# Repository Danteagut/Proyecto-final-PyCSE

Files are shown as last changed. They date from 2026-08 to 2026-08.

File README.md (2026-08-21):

Motor Dron — Control de Altura por Realimentación Negativa

Trabajo práctico de posgrado en Sistemas Embebidos. Control de altura en lazo cerrado de un "drone conceptual" (motor DC + hélice sobre un banco de pruebas), implementado sobre un STM32F446RE (Nucleo-F446RE), con telemetría y consigna remota por Bluetooth Low Energy y un dashboard en Node-RED.

Qué hace

Un sensor ultrasónico HC-SR04 mide la altura real del conjunto. Un controlador PID corre en el STM32 a 10 Hz, compara esa altura contra un setpoint (objetivo) recibido de forma remota, y ajusta el empuje del motor (PWM sobre un puente H L298N) para sostenerlo en esa altura. El setpoint se manda con un simple comando de texto (HEIGHT:<cm>) desde un celular por BLE o desde la PC por el propio cable USB del ST-Link, y la telemetría se puede visualizar en tiempo real en un dashboard de Node-RED.

 objetivo (cm) ──►(+)──► error ──► PID ──► saturación ──► motor (PWM) ──► planta (altura real)
                   ▲                                                            │
                   └──────────────────── retroalimentación negativa (HC-SR04) ─────┘

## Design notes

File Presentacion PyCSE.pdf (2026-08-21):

# Control de altura por realimentación negativa

# Motor Dron TP — Sistemas Embebidos de Posgrado

### Desarrollo de drone para control de cultivos y desmalezado

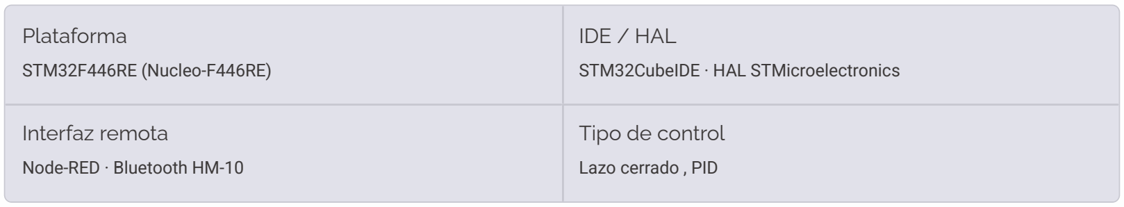
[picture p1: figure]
Plataforma; STM32F446RE (Nucleo-F446RE); IDE / HAL; STM32CubeIDE · HAL STMicroelectronics; Interfaz remota; Node-RED · Bluetooth HM-10; Tipo de control; Lazo cerrado , PID

# Punto de partida: El proyecto original

El firmware inicial consistía en un único main.c que combinaba dos perifericos independientes, sin ningún lazo de control entre ellos.

# Experimento 1 — Control de velocidad motor DC

### - ADC1 en PA4 (canal 4) con filtro de promedio móvil de 16

### muestras - PWM de 1 kHz generado por TIM2_CH1 / PA5 → driver L298N (ENA)

### - Sentido fijo adelante: IN1/IN2 en PB5/PB10

### - Velocidad controlada directamente por el potenciómetro analógico

# Experimento 2 — Medición de distancia HC-SR04

### - TIM1 en modo Input Capture: TRIG en PA9, ECHO en

### PA8/TIM1_CH1 - Cálculo de ancho de pulso → distancia en cm - Reporte por USART2 a 115200 baud al ST-Link (terminal serie)

### - Frecuencia de muestreo: ~1 Hz

Punto crítico: Motor y sensor NO estaban conectados entre sí. La distancia se medía pero no influía en la velocidad. No existía lazo de control, Bluetooth ni Node-RED.

# Objetivo del rediseño

Transformar el banco de pruebas en un verdadero sistema de control automático en lazo cerrado, eliminando la entrada manual del potenciómetro y habilitando operación remota.

### 1 Retroalimentacion real

La distancia medida por el HC-SR04 se convierte en la
variable de retroalimentación que ajusta automáticamente velocidad y sentido del motor en cada ciclo de control.

### 2 Setpoint remoto

La altura objetivo (setpoint en cm) es configurable de forma remota por Bluetooth desde un dashboard Node-RED, sin recompilar ni reconectar el hardware.

### 3 Telemetría continua

El sistema emite telemetría a 2 Hz (altura, setpoint, velocidad aplicada) hacia Node-RED para visualización en tiempo real y análisis de respuesta al escalón.

### Diagrama de bloques — Lazo de realimentación negativa

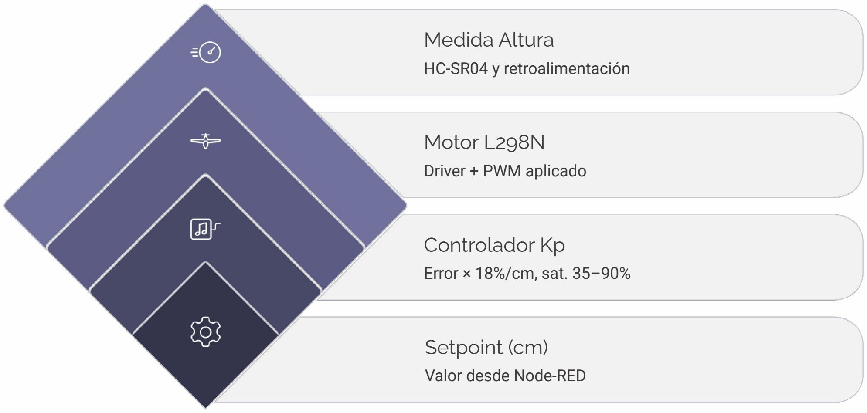
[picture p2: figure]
Medida Altura; HC-SR04 y retroalimentación; Motor L298N; Driver + PWM aplicado; Controlador Kp; Error × 18%/cm, sat. 35–90%; Setpoint (cm); Valor desde Node-RED

El error se calcula como e = setpoint − altura_actual. Una zona muerta de ±0.5 cm evita chattering por ruido de medición. El lazo opera a 10 Hz; la telemetría se emite a 2 Hz de forma desacoplada.

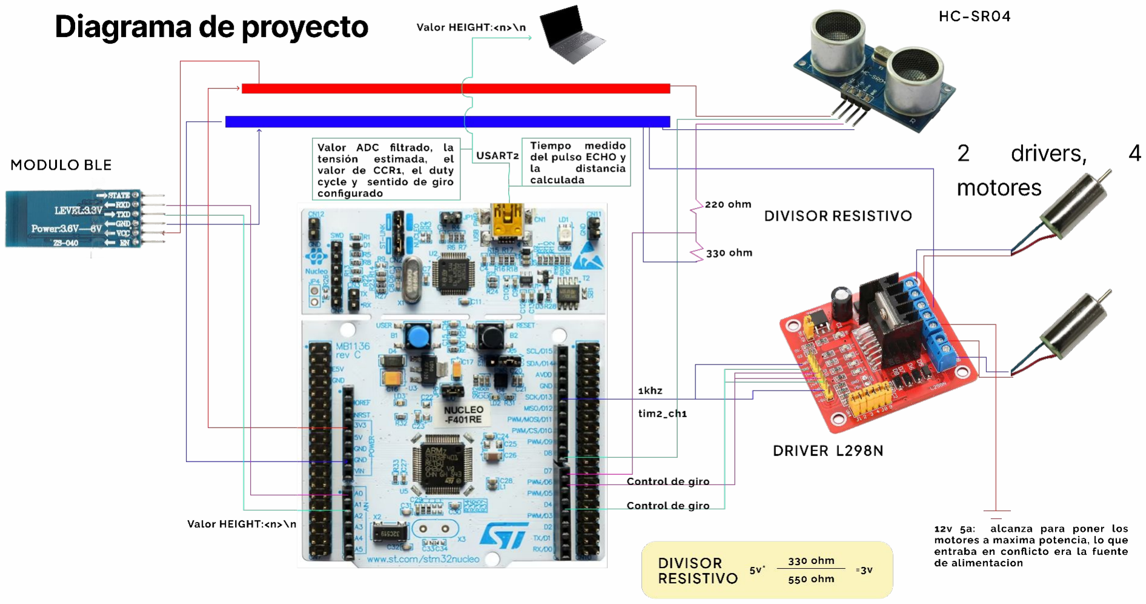
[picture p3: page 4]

# Arquitectura de software: La modularidad

La reorganización completa en módulos independientes (carpetas Src/ e Inc/) es la decisión arquitectónica central del rediseño. Cada módulo tiene responsabilidad única, es testeable de forma aislada y reemplazable sin afectar al resto.

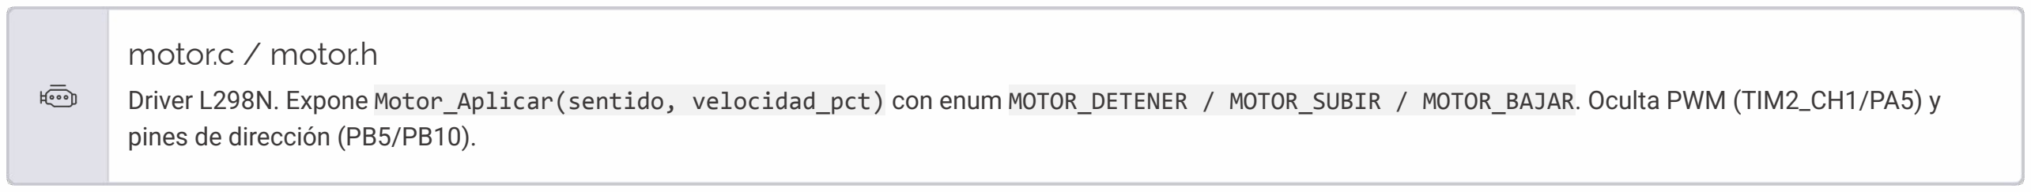
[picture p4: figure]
motor.c / motor.h; pines de dirección (PB5/PB10).

Driver L298N. Expone Motor_Aplicar(sentido, velocidad_pct) con enum MOTOR_DETENER / MOTOR_SUBIR / MOTOR_BAJAR. Oculta PWM (TIM2_CH1/PA5) y

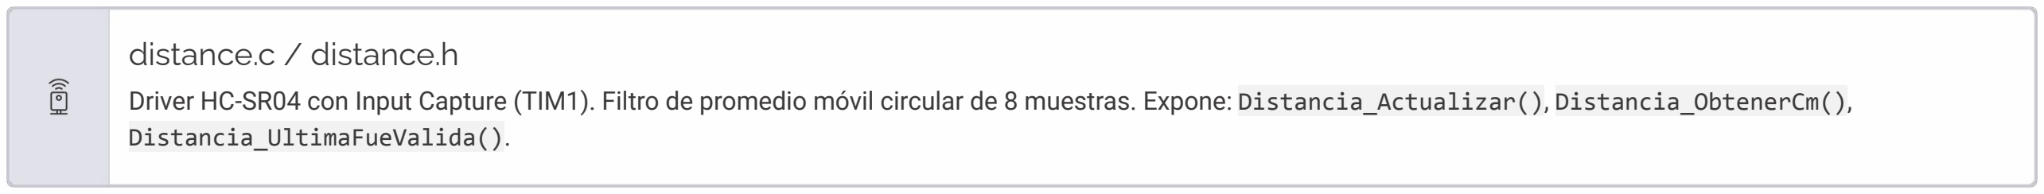
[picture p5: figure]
distance.c / distance.h; Distancia_UltimaFueValida().

Driver HC-SR04 con Input Capture (TIM1). Filtro de promedio móvil circular de 8 muestras. Expone: Distancia_Actualizar(), Distancia_ObtenerCm(),

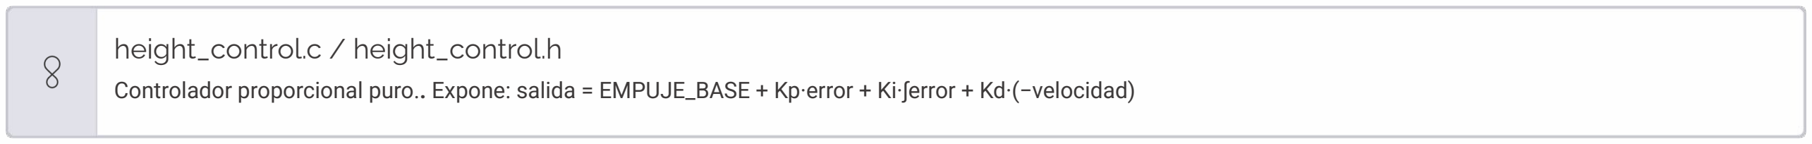
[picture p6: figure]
height_control.c / height_control.h

Controlador proporcional puro.. Expone: salida = EMPUJE_BASE + Kp·error + Ki·∫error + Kd·(−velocidad)

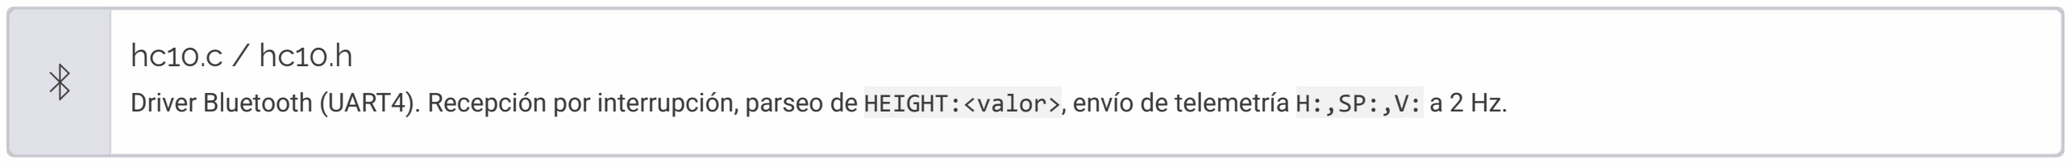
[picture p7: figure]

Driver Bluetooth (UART4). Recepción por interrupción, parseo de HEIGHT:<valor>, envío de telemetría H:,SP:,V: a 2 Hz.

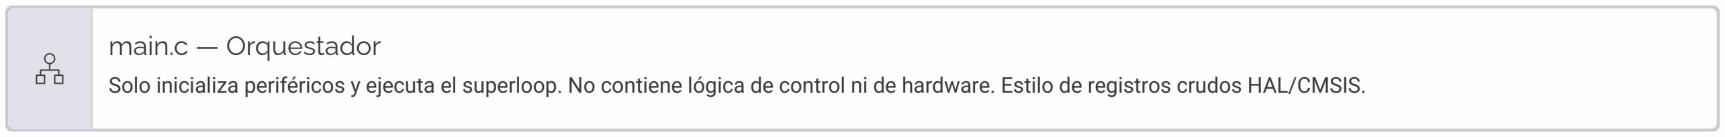
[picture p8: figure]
main.c — Orquestador

Solo inicializa periféricos y ejecuta el superloop. No contiene lógica de control ni de hardware. Estilo de registros crudos HAL/CMSIS.

# Tabla de conexionado físico (pines)

Asignación completa de pines del Nucleo-F446RE para el sistema integrado. GND común obligatorio entre fuente de motor y STM32 (falla real detectada y corregida en puesta en marcha).

Función | Pin Nucleo | Periférico / Notas | Subsistema
ENA (PWM) | PA5 | TIM2_CH1, 1 kHz, duty cycle 35–90% | Motor L298N
IN1 (dirección) | PB5 | GPIO salida digital | Motor L298N
IN2 (dirección) | PB10 | GPIO salida digital | Motor L298N
TRIG | PA9 | GPIO salida, pulso 10 µs | HC-SR04
ECHO | PA8 | TIM1_CH1, Input Capture | HC-SR04
TX módulo BT | PA1 | UART4_RX, 9600 baud | Bluetooth Hm-10 (bt05)
RX módulo BT | PA0 | UART4_TX, 9600 baud | Bluetooth Hm-10 (bt05)
TX debug | PA2 | USART2, 115200 baud (ST-Link) | Debug
RX debug | PA3 | USART2, 115200 baud (ST-Link) | Debug

USART2 y UART4 son periféricos separados deliberadamente para evitar contención entre tráfico de debug (115200 baud) y tráfico Bluetooth (9600 baud). Nunca comparten bus.

# Sistema de control: Lazo de realimentación negativa

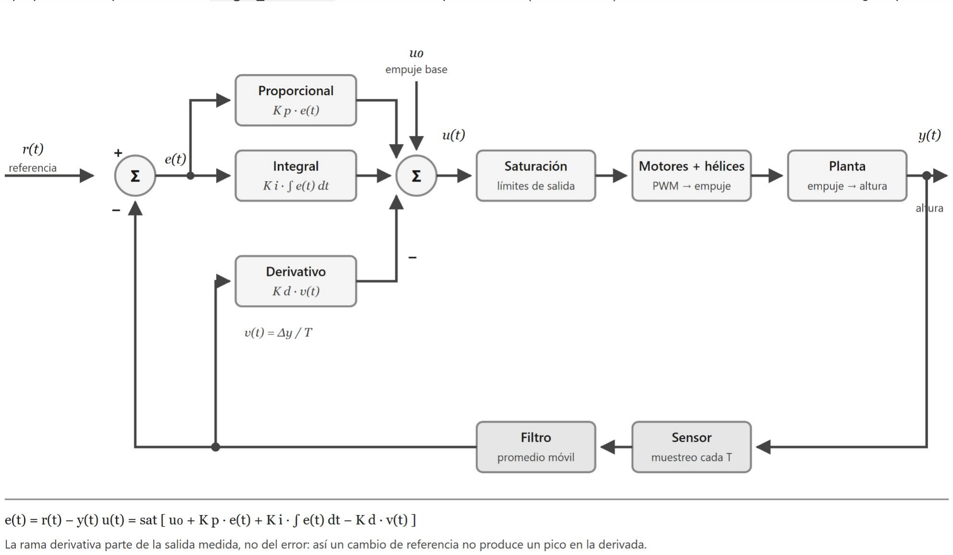
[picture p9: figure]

Ley de control proporcional implementada en height_control.c. El controlador opera a 10 Hz (cada 100 ms), frecuencia aumentada desde 1 Hz original para reducir overshoot.

# Sistema de control: Lazo de realimentación negativa

Ley de control proporcional implementada en height_control.c. El controlador opera a 10 Hz (cada 100 ms), frecuencia aumentada desde 1 Hz original para reducir overshoot.

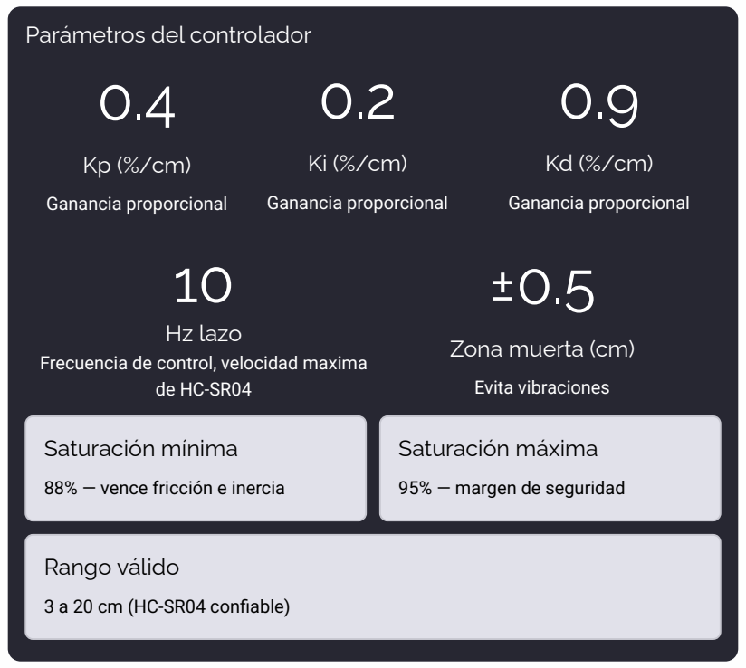
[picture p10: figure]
Parámetros del controlador 0.4; Ganancia proporcional; Zona muerta (cm); Evita vibraciones; Hz lazo; Frecuencia de control, velocidad maxima de HC-SR04; Saturación mínima; 88% — vence fricción e inercia; Saturación máxima; 95% — margen de seguridad; Rango válido; 3 a 20 cm (HC-SR04 confiable)

# Comunicación Bluetooth: Protocolo y hardware

Enlace Bluetooth completo agregado al sistema. Implementado sobre UART4 (PA0/PA1) a 9600 baud. El hardware real identificado es un HM-10 (breakout ZS-040, Bluetooth clásico/SPP).

## Protocolo de entrada — Comando remoto desde Node-RED

HEIGHT:<valor_cm>\n

Ejemplo: HEIGHT:15\n fija el setpoint a 15 cm. El módulo hc10.c recibe por interrupción y parsea el token HEIGHT: antes de llamar a ControlAltura_FijarObjetivoCm().

## Protocolo de salida — Telemetría a 2 Hz

H:<altura>,SP:<setpoint>,V:<velocidad_pct>\n

## Puesta en marcha del módulo HM-10

## Identificación del hardware

El módulo real es HM-10 (BT05). Diferencia crítica: utiliza la estructura de un modulo hc05 entonces la computadora no lo reconoce como ble y no puedo enviar comandos

## Firmware puente standalone

Herramienta de soporte: firmware que usa el ST-Link como adaptador USB-TTL para enviar comandos AT al HM-10

USART2 emite simultáneamente mensajes legibles por humanos a 115200 baud para depuración en terminal serie, en paralelo al tráfico Bluetooth.

# Dashboard en Node-RED: Interfaz de usuario remota

Flujo control-altura-dashboard.json — HMI/SCADA, permite ensayos sin recompilar y separa la visualización de la lógica de control embebida.

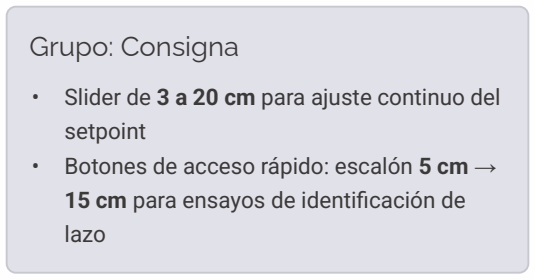
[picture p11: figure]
Grupo: Consigna; setpoint; 15 cm para ensayos de identificación de; lazo

- Slider de 3 a 20 cm para ajuste continuo del
- Botones de acceso rápido: escalón 5 cm →

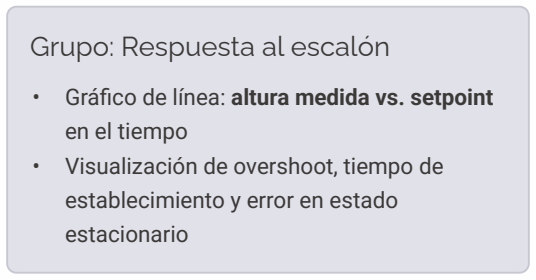
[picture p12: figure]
Grupo: Respuesta al escalón; en el tiempo; • Visualización de overshoot, tiempo de; establecimiento y error en estado; estacionario

- Gráfico de línea: altura medida vs. setpoint

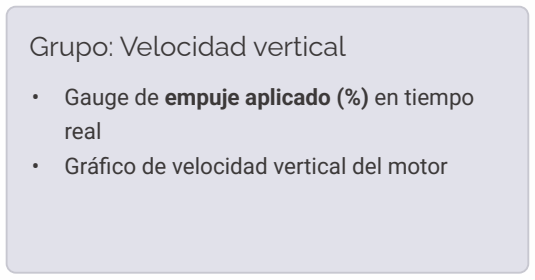
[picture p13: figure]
Grupo: Velocidad vertical; real

- Gauge de empuje aplicado (%) en tiempo
- Gráfico de velocidad vertical del motor

## Nodo function — "Formatear HEIGHT"

## Nodo function — "Parsear telemetría"

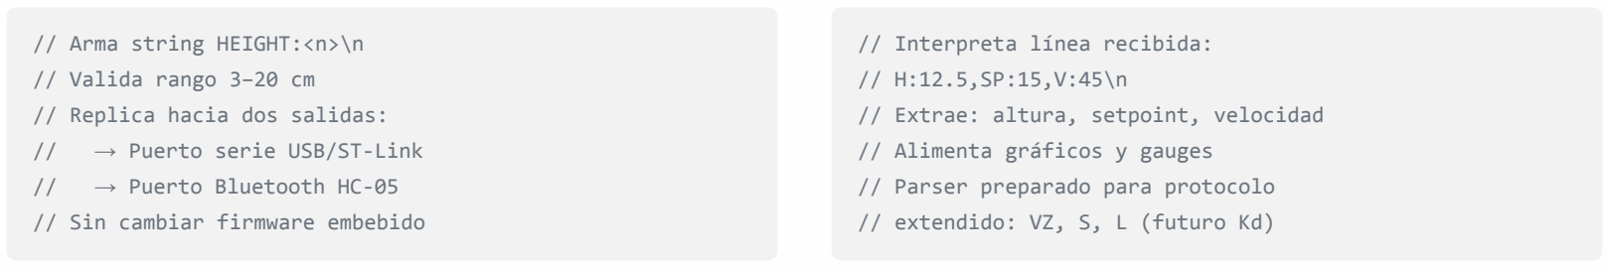
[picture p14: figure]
// Arma string HEIGHT:<n>\n; // Valida rango 3–20 cm; // Replica hacia dos salidas:; → Puerto serie USB/ST-Link; → Puerto Bluetooth HC-05; // Sin cambiar firmware embebido; // Interpreta línea recibida:; // Extrae: altura, setpoint, velocidad; // Alimenta gráficos y gauges; // Parser preparado para protocolo; // extendido: VZ, S, L (futuro Kd)

# Valor K : Valores 01

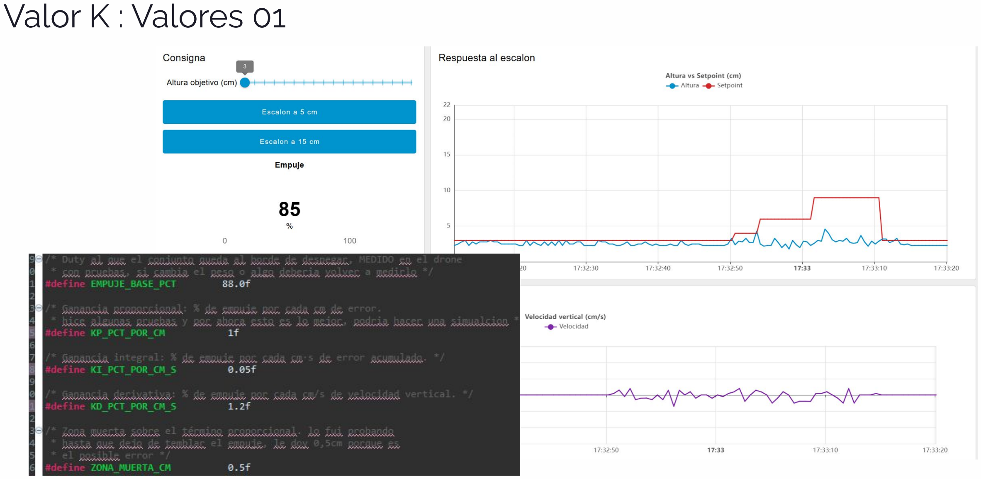
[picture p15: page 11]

# Valor K : Valores 02

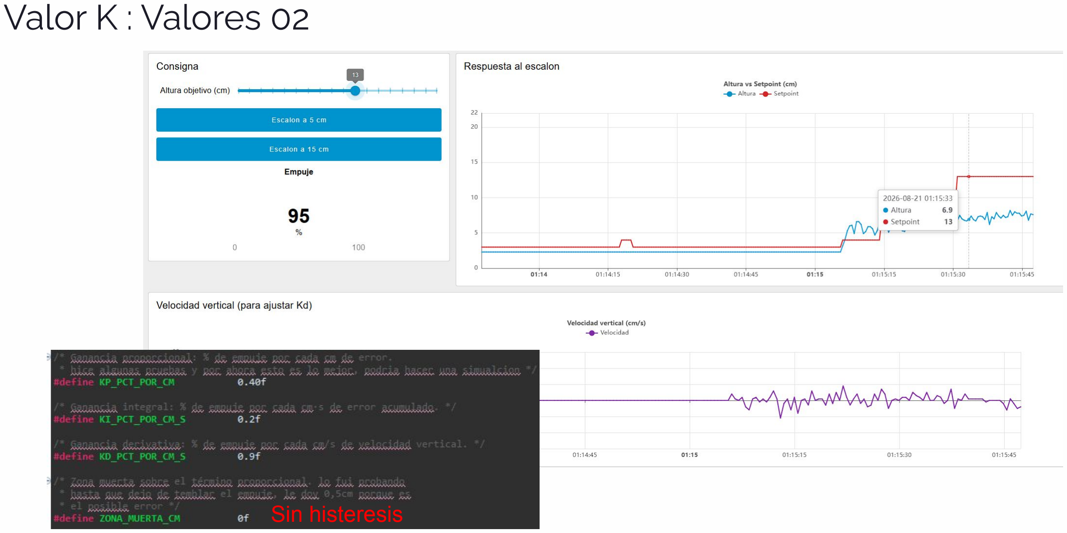
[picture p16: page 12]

## Sin histeresis

# Valor K : Valores 03

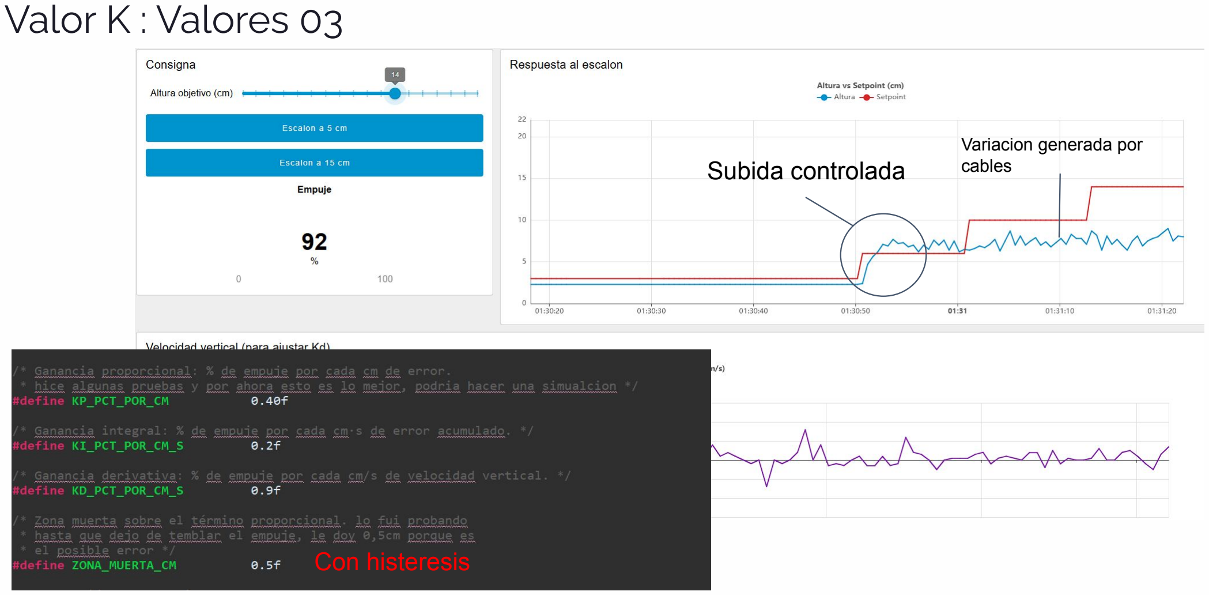
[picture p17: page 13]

## Subida controlada

### Variacion generada por cables

## Con histeresis

# Tabla comparativa: Proyecto original vs. Rediseñado

El salto cualitativo entre ambas versiones abarca organización del código, arquitectura de control, comunicaciones e interfaz de usuario. La tabla resume las siete dimensiones de comparación.

Aspecto | Proyecto original | Proyecto rediseñado
Organización del código | Único main.c monolítico, sin separación de responsabilidades | Módulos separados: motor.c, distance.c, height_control.c, hc10.c, main.c orquestador
Entrada del sistema | Potenciómetro analógico (ADC manual, PA4) | Setpoint remoto por Bluetooth o directo desde dashboard Node-RED (HEIGHT:<n>\n)
Relación motor–sensor | Independientes, sin lazo. Distancia medida pero ignorada por el motor | Lazo cerrado de realimentación negativa con control proporcional (Kp = 18 %/cm)
Frecuencia de actualización | Sensor a ~1 Hz, sin control automático | Control a 10 Hz, telemetría a 2 Hz, desacoplados
Comunicación | Solo USART2 a 115200 baud (debug local, terminal serie) | USART2 (debug) + UART4/HC-05 Bluetooth (comando y telemetría remota, 9600 baud)
Interfaz de usuario | Ninguna (terminal serie cruda, lectura manual) | Dashboard Node-RED: slider, botones de escalón, gráficos de respuesta, gauge de empuje
Alcance de motores | 1 motor / 1 canal L298N en firmware único | 1 motor en firmware principal + variante experimental de 4 motores (variante_4_motores) aislada del código de producción

lazo cerrado proporcional con zona muerta y

De terminal serie local a protocolo Bluetooth protocolo extendido VZ/S/L, variante de 4

# Puntos de mejora

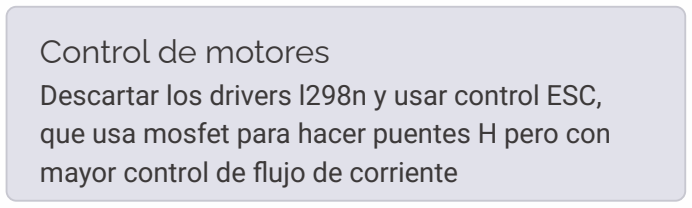
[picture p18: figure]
Control de motores; mayor control de flujo de corriente

Descartar los drivers l298n y usar control ESC,

## que usa mosfet para hacer puentes H pero con

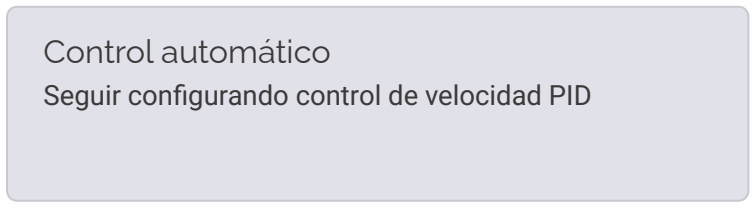
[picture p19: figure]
Control automático

## Seguir configurando control de velocidad PID

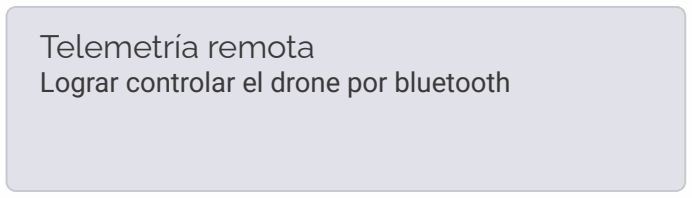
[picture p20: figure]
Telemetría remota; Lograr controlar el drone por bluetooth
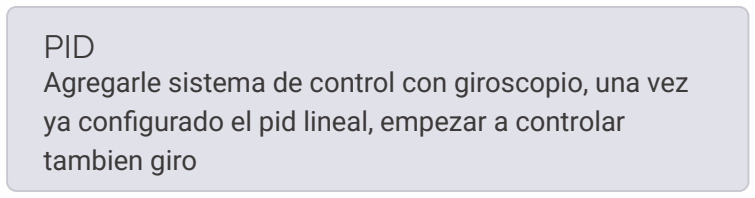
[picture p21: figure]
PID; tambien giro

## Agregarle sistema de control con giroscopio, una vez ya configurado el pid lineal, empezar a controlar

# Muchas gracias

# Dante Gutierrez LSE / PyCSE 21/08/2026

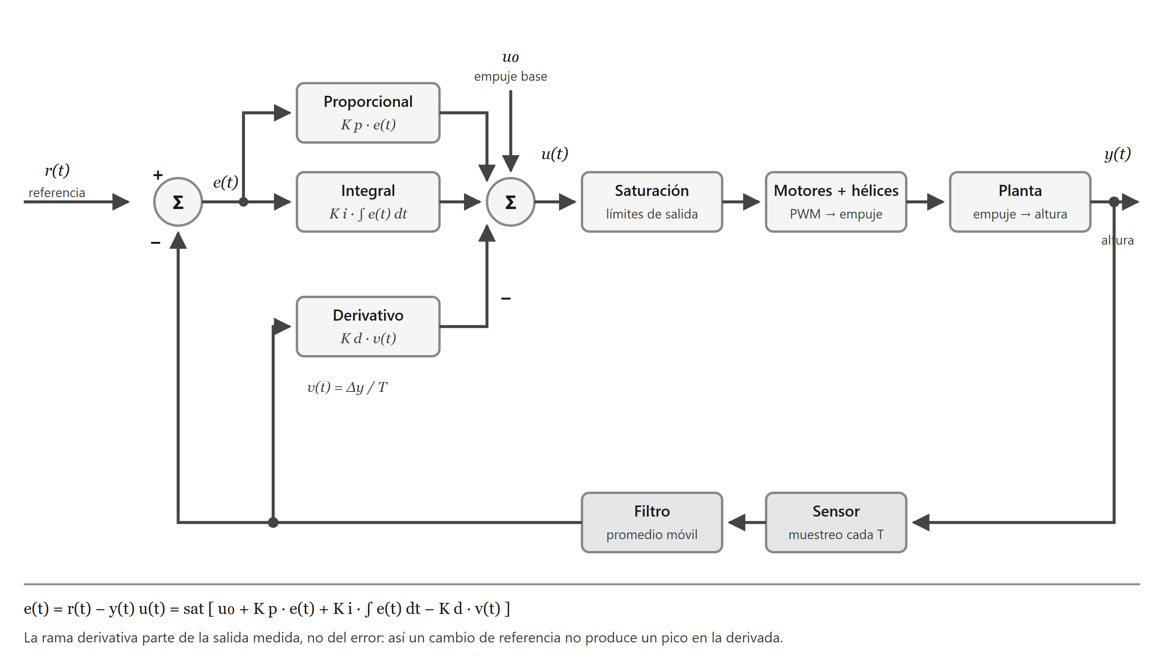
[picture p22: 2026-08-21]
Documentacion/diagrama-control-pid.png

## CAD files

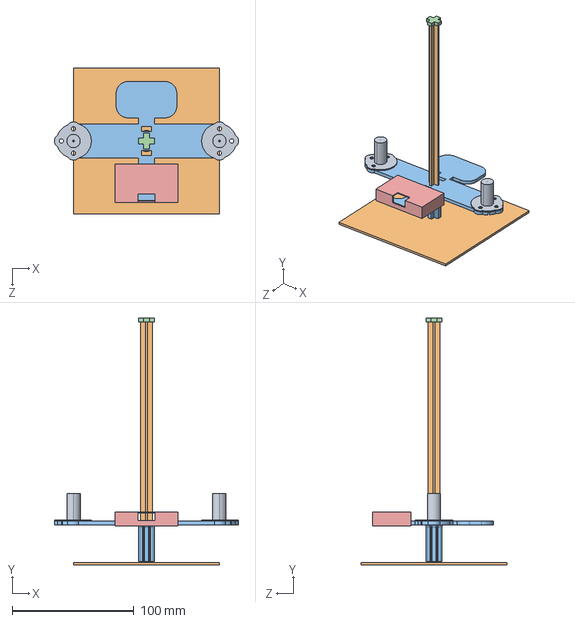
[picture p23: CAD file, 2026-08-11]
Introduccion a sistemas embebidos/Modelado de drone.STEP
151.5 x 203.2 x 120.0 mm

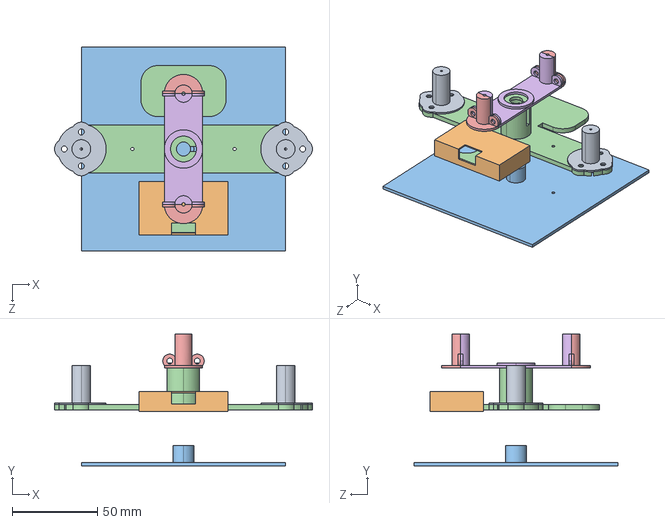
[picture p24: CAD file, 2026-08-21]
Modelado de drone.STEP
151.5 x 77.5 x 120.0 mm

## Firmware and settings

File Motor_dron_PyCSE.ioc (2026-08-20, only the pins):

Mcu.UserName=STM32F446RETx
PA0-WKUP.Signal=UART4_TX
PA1.Signal=UART4_RX
PA13.GPIO_Label=TMS
PA13.Signal=SYS_JTMS-SWDIO
PA14.GPIO_Label=TCK
PA14.Signal=SYS_JTCK-SWCLK
PA2.GPIO_Label=USART_TX
PA2.Signal=USART2_TX
PA3.GPIO_Label=USART_RX
PA3.Signal=USART2_RX
PA5.Signal=S_TIM2_CH1
PA8.Signal=S_TIM1_CH1
PA9.GPIO_Label=HCSR04_TRIG
PA9.Signal=GPIO_Output
PB10.GPIO_Label=L298N_IN2
PB10.Signal=GPIO_Output
PB3.GPIO_Label=SWO
PB3.Signal=SYS_JTDO-SWO
PB5.GPIO_Label=L298N_IN1
PB5.Signal=GPIO_Output
PC13.GPIO_Label=B1 [Blue PushButton]
PC13.Signal=GPXTI13
PC14-OSC32_IN.Signal=RCC_OSC32_IN
PC15-OSC32_OUT.Signal=RCC_OSC32_OUT
PH0-OSC_IN.Signal=RCC_OSC_IN
PH1-OSC_OUT.Signal=RCC_OSC_OUT

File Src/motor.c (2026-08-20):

#include "motor.h"
#include "main.h"

/* Driver L298N + PWM (TIM2_CH1/PA5) existente, modularizado.
 * La velocidad la determina el lazo proporcional de height_control,
 * no Node-RED ni el potenciómetro. */
#define PWM_PERIODO_CUENTAS               1000UL   /* ARR + 1 */

#define L298N_PIN_IN1                     5U       /* PB5  - D4 */
#define L298N_PIN_IN2                     10U      /* PB10 - D6 */

/* FORWARD (IN1=1,IN2=0) hace que la altura
 * medida por el sensor AUMENTE => FORWARD = MOTOR_SUBIR. */

/* Configura TIM2_CH1 sobre PA5 como salida PWM de 1 kHz (señal ENA del L298N). */
static void Configurar_PWM_TIM2_PA5(void)
{
    RCC->AHB1ENR |= RCC_AHB1ENR_GPIOAEN;
    (void)RCC->AHB1ENR;

    GPIOA->MODER &= ~(3UL << (5U * 2U));
    GPIOA->MODER |=  (2UL << (5U * 2U));
    GPIOA->OTYPER &= ~(1UL << 5U);
    GPIOA->OSPEEDR &= ~(3UL << (5U * 2U));
    GPIOA->OSPEEDR |=  (2UL << (5U * 2U));
    GPIOA->PUPDR &= ~(3UL << (5U * 2U));

    GPIOA->AFR[0] &= ~(0xFUL << (5U * 4U));
    GPIOA->AFR[0] |=  (1UL   << (5U * 4U));

    RCC->APB1ENR |= RCC_APB1ENR_TIM2EN;
    (void)RCC->APB1ENR;

    TIM2->CR1 &= ~TIM_CR1_CEN;

    TIM2->PSC = 83U;
    TIM2->ARR = 999U;
    TIM2->CNT = 0U;
    TIM2->CCR1 = 0U;

    TIM2->CCMR1 &= ~TIM_CCMR1_CC1S;
    TIM2->CCMR1 &= ~TIM_CCMR1_OC1M;
    TIM2->CCMR1 |=  (6UL << 4U);
    TIM2->CCMR1 |= TIM_CCMR1_OC1PE;

    TIM2->CCER &= ~TIM_CCER_CC1P;
    TIM2->CCER |=  TIM_CCER_CC1E;

    TIM2->CR1 |= TIM_CR1_ARPE;
    TIM2->CR1 &= ~TIM_CR1_CMS;
    TIM2->CR1 &= ~TIM_CR1_DIR;

    TIM2->EGR |= TIM_EGR_UG;
    TIM2->CR1 |= TIM_CR1_CEN;
}

/* Traduce un porcentaje de velocidad (0-100) al registro de comparación
 * del PWM, que es lo que define el duty cycle sobre el pin ENA. */
static void Motor_FijarVelocidadPorcentaje(uint32_t porcentaje)
{
    if (porcentaje > 100UL)
    {
        porcentaje = 100UL;
    }

    TIM2->CCR1 = (porcentaje * PWM_PERIODO_CUENTAS) / 100UL;
}

/* Configura PB5/PB10 como salidas digitales para IN1/IN2 del L298N. */
static void Configurar_PinesDireccion_L298N(void)
{
    RCC->AHB1ENR |= RCC_AHB1ENR_GPIOBEN;
    (void)RCC->AHB1ENR;

    GPIOB->MODER &= ~((3UL << (L298N_PIN_IN1 * 2U)) | (3UL << (L298N_PIN_IN2 * 2U)));
    GPIOB->MODER |=  ((1UL << (L298N_PIN_IN1 * 2U)) | (1UL << (L298N_PIN_IN2 * 2U)));
    GPIOB->OTYPER &= ~((1UL << L298N_PIN_IN1) | (1UL << L298N_PIN_IN2));
    GPIOB->OSPEEDR &= ~((3UL << (L298N_PIN_IN1 * 2U)) | (3UL << (L298N_PIN_IN2 * 2U)));
    GPIOB->PUPDR &= ~((3UL << (L298N_PIN_IN1 * 2U)) | (3UL << (L298N_PIN_IN2 * 2U)));
}

/* IN1=1, IN2=0: gira en el sentido que hace SUBIR la altura. */
static void Motor_GirarAdelante(void)
{
    GPIOB->BSRR = (1UL << L298N_PIN_IN2) | (1UL << (L298N_PIN_IN1 + 16U));
}

/* IN1=0, IN2=1: gira en el sentido que hace BAJAR la altura. */
static void Motor_GirarAtras(void)
{
    GPIOB->BSRR = (1UL << (L298N_PIN_IN2 + 16U)) | (1UL << L298N_PIN_IN1);
}

/* IN1=0, IN2=0: frena el motor (rueda libre / freno según el driver). */
static void Motor_Detener(void)
{
    GPIOB->BSRR = (1UL << (L298N_PIN_IN1 + 16U)) | (1UL << (L298N_PIN_IN2 + 16U));
}

/* Inicializa PWM y dirección, y deja el motor detenido con duty en cero. */
void Motor_Inicializar(void)
{
    Configurar_PWM_TIM2_PA5();
    Configurar_PinesDireccion_L298N();
    Motor_Detener();
    Motor_FijarVelocidadPorcentaje(0UL);
}

/* Aplica el resultado del lazo proporcional: primero el sentido en IN1/IN2
 * y después el duty del PWM sobre ENA. Al detener fuerza duty 0. */
void Motor_Aplicar(MotorComando_t sentido, uint8_t velocidad_pct)
{
    switch (sentido)
    {
        case MOTOR_SUBIR:
            Motor_GirarAdelante();
            Motor_FijarVelocidadPorcentaje((uint32_t)velocidad_pct);
            break;

        case MOTOR_BAJAR:
            Motor_GirarAtras();
            Motor_FijarVelocidadPorcentaje((uint32_t)velocidad_pct);
            break;

        case MOTOR_DETENER:
        default:
            Motor_Detener();
            Motor_FijarVelocidadPorcentaje(0UL);
            break;
    }
}

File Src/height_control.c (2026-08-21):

#include "height_control.h"
#include "motor.h"
#include <math.h>

/* ---------------------------------------------------------------------------
 * Lazo PID con base de empuje, para elevación por HÉLICES.
 *
 *   salida = EMPUJE_BASE + Kp·error + Ki·∫error + Kd·(−velocidad)
 *
 * Orden de importancia: primero D (estabilidad), después I (precisión).
 * Un P+I sin D sobre esta planta es inestable; el D tiene que estar puesto.
 *
 *  * ------------------------------------------------------------------------- */

/* El HC-SR04 no mide de forma confiable por debajo de ~2 cm. */
#define ALTURA_MIN_CM          3.0f
#define ALTURA_MAX_CM          20.0f

/* Duty al que el conjunto queda al borde de despegar, MEDIDO en el drone
 * con pruebas, si cambia el peso o algo deberia volver a medirlo */
#define EMPUJE_BASE_PCT        88.0f

/* Ganancia proporcional: % de empuje por cada cm de error.
 * hice algunas pruebas y por ahora esto es lo mejor, podria hacer una simualcion */
#define KP_PCT_POR_CM           0.40f

/* Ganancia integral: % de empuje por cada cm·s de error acumulado. */
#define KI_PCT_POR_CM_S         0.2f

/* Ganancia derivativa: % de empuje por cada cm/s de velocidad vertical. */
#define KD_PCT_POR_CM_S         0.9f

/* Zona muerta sobre el término proporcional. lo fui probando
 * hasta que dejo de temblar el empuje, le doy 0,5cm porque es
 * el posible error */
#define ZONA_MUERTA_CM          0.5f

/* Saturación de la salida, alrededor de la base.
 * El mínimo no es cero: conviene que las hélices sigan girando para no
 * pagar el tiempo de arranque cada vez que hay que descender. */
#define SALIDA_MIN_PCT         40.0f
#define SALIDA_MAX_PCT         95.0f

#define PERIODO_S              ((float)CONTROL_PERIODO_MS / 1000.0f)

static float   objetivo_cm         = ALTURA_MIN_CM;
static float   error_cm            = 0.0f;
static float   velocidad_cm_s      = 0.0f;
static float   altura_anterior_cm  = 0.0f;
static uint8_t hay_altura_anterior = 0U;
static uint8_t empuje_pct          = 0U;

/* Acumulador del término integral, en % de empuje. */
static float   integral_pct        = 0.0f;

/* Mientras valga 0 el lazo no mueve el motor. Evita que al encender, con
 * un setpoint que el operador todavía no eligió, las hélices arranquen
 * solas. Se habilita con el primer HEIGHT válido. */
static uint8_t objetivo_recibido   = 0U;

/* Deja el lazo en reposo: motores frenados, esperando el primer setpoint. */
void ControlAltura_Inicializar(void)
{
    objetivo_cm         = ALTURA_MIN_CM;
    error_cm            = 0.0f;
    velocidad_cm_s      = 0.0f;
    altura_anterior_cm  = 0.0f;
    hay_altura_anterior = 0U;
    empuje_pct          = 0U;
    integral_pct        = 0.0f;
    objetivo_recibido   = 0U;

    Motor_Aplicar(MOTOR_DETENER, 0U);
}

/* Guarda el setpoint recibido por HC-10, limitado estrictamente a 3-20 cm. */
void ControlAltura_FijarObjetivoCm(float objetivo)
{
    if (objetivo < ALTURA_MIN_CM)
    {
        objetivo = ALTURA_MIN_CM;
    }
    else if (objetivo > ALTURA_MAX_CM)
    {
        objetivo = ALTURA_MAX_CM;
    }

    objetivo_cm       = objetivo;
    objetivo_recibido = 1U;   /* habilita el lazo */
}

/* Una iteración del lazo PD. */
void ControlAltura_Actualizar(float altura_actual_cm)
{
    float termino_p;
    float termino_d;
    float salida_pct;
    float salida_sin_saturar;

    /* Sin setpoint elegido todavía, las hélices no giran. */
    if (objetivo_recibido == 0U)
    {
        error_cm            = 0.0f;
        velocidad_cm_s      = 0.0f;
        empuje_pct          = 0U;
        integral_pct        = 0.0f;
        altura_anterior_cm  = altura_actual_cm;
        hay_altura_anterior = 1U;

        Motor_Aplicar(MOTOR_DETENER, 0U);
        return;
    }

    /* --- Velocidad vertical -------------------------------------------
     * Se deriva la ALTURA MEDIDA, no el error. Si se derivara el error,
     * cada vez que Node-RED manda un setpoint nuevo el salto brusco
     * produciría un pico enorme en la derivada
     *
     * Además la altura ya viene filtrada por el promedio móvil: derivar
     * la señal cruda amplificaría el ruido del sensor. */
    if (hay_altura_anterior == 0U)
    {
        velocidad_cm_s = 0.0f;   /* primera iteración: no hay con qué comparar */
        hay_altura_anterior = 1U;
    }
    else
    {
        velocidad_cm_s = (altura_actual_cm - altura_anterior_cm) / PERIODO_S;
    }

    altura_anterior_cm = altura_actual_cm;

    /* --- Realimentación negativa --------------------------------------- */
    error_cm = objetivo_cm - altura_actual_cm;

    /* --- Término proporcional -----------------------------------------
     * Sin valor absoluto ni lógica de signo: si el error es negativo
     * (está por encima del objetivo) el término resta empuje y el
     * conjunto baja solo. La gravedad hace el trabajo. */
    if (fabsf(error_cm) <= ZONA_MUERTA_CM)
    {
        termino_p = 0.0f;
    }
    else
    {
        termino_p = KP_PCT_POR_CM * error_cm;
    }

    /* --- Término derivativo -------------------------------------------
     * Signo negativo: si el conjunto sube, descuenta empuje para frenar
     * antes de alcanzar el objetivo. */
    termino_d = -KD_PCT_POR_CM_S * velocidad_cm_s;

    salida_sin_saturar = EMPUJE_BASE_PCT + termino_p + integral_pct + termino_d;

    /* --- Saturación ---------------------------------------------------- */
    salida_pct = salida_sin_saturar;

    if (salida_pct > SALIDA_MAX_PCT)
    {
        salida_pct = SALIDA_MAX_PCT;
    }
    else if (salida_pct < SALIDA_MIN_PCT)
    {
        salida_pct = SALIDA_MIN_PCT;
    }

    /* --- Término integral, con ANTI-WINDUP -----------------------------
     * Sólo se acumula si la salida NO está saturada. sino se haria infinito*/
    if ((salida_pct == salida_sin_saturar) && (KI_PCT_POR_CM_S > 0.0f))
    {
        integral_pct += KI_PCT_POR_CM_S * error_cm * PERIODO_S;
    }

    empuje_pct = (uint8_t)salida_pct;

    /* Las hélices giran en un solo sentido: el sentido NUNCA se invierte.
     * Para descender se reduce el empuje y baja por su propio peso. */
    Motor_Aplicar(MOTOR_SUBIR, empuje_pct);
}

/* Setpoint vigente, en cm. */
float ControlAltura_ObtenerObjetivoCm(void)
{
    return objetivo_cm;
}

/* Error de la última iteración (objetivo - altura), en cm. */
float ControlAltura_ObtenerErrorCm(void)
{
    return error_cm;
}

/* Velocidad vertical estimada, en cm/s. Positiva = subiendo. */
float ControlAltura_ObtenerVelocidadVerticalCmS(void)
{
    return velocidad_cm_s;
}

/* Empuje que el lazo le pidió a los motores, en %. */
uint8_t ControlAltura_ObtenerEmpujePct(void)
{
    return empuje_pct;
}
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

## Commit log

2026-08-11 cambios en el proyecto, modularizacion y uso de node red.
    [Modelado de drone.STEP]
2026-08-20 codigo base, falta actualizar el pid
2026-08-21 video de presentacion y pdf preliminar
2026-08-21 elimine archivos antiguos variable 4 motores
2026-08-21 presentacion y step actualizados
    [Modelado de drone.STEP]
2026-08-21 presentacion para defensa
